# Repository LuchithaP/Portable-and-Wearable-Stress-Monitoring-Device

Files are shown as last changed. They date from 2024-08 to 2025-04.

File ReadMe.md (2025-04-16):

# Portable and Wearable Stress Monitoring Device

A wearable health monitoring system that tracks multiple physiological parameters to help users monitor and manage stress levels.

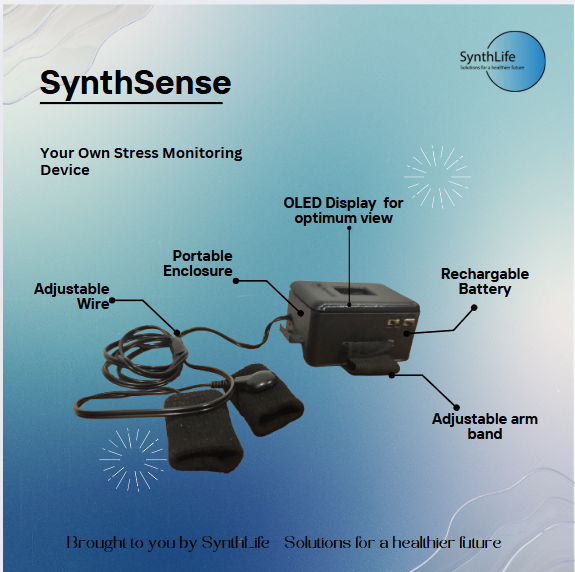
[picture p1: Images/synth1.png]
Device Image


## Overview

This project was developed as part of the EN1190-Engineering Design Project. The device combines multiple sensors to accurately measure physiological indicators of stress and provide real-time feedback to users.

## Features

- **Portable and Wearable Design**: Compact form factor for everyday use
- **Multi-Sensor Approach**: Uses multiple physiological parameters for more accurate stress detection
- **Real-Time Monitoring**: Provides immediate feedback on current stress levels
- **User-Friendly Interface**: Simple display with easy-to-understand stress level indicators

## Hardware Components

### Main Components
- ESP12E microcontroller with built-in WiFi
- Galvanic Skin Response (GSR) sensor
- Temperature sensor (MLX90614)
- Heart rate and SpO2 sensor (MAX30100)
- OLED Display (DM0037)
- 3.7V 1000mAh Rechargeable LiPo Battery

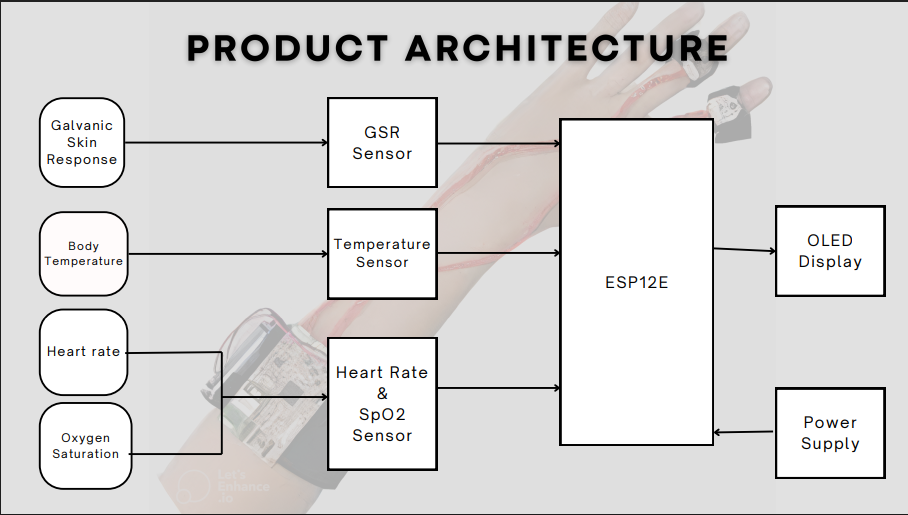
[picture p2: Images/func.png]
Hardware Block Diagram


### Hardware Specifications

#### ESP12E
- Operating voltage: 2.2V to 3.6V
- Operating temperature: -40°C to +125°C
- Working current: 240mA (MAX)
- Built-in WiFi capability

#### Heart Rate & SpO2 Sensor (MAX30100)
- Operating voltage: 1.8V to 3.3V
- Fast data output capability
- Built-in temperature sensor for environmental compensation

#### Temperature Sensor (MLX90614)
- Operating voltage: 3-5V
- Range: -40°C to +125°C (ambient) | -70°C to 380°C (object)
- Accuracy: ±0.5°C

#### Galvanic Skin Response Sensor
- Operating voltage: 3.3-5V
- Measures electrical conductance of skin

#### OLED Display (DM0037)
- Operating voltage: 3.3V–5V DC
- Low power consumption: 0.04W during normal operation
- Working temperature: -30°C to 80°C

## Shematic Design
The schematic was designed using Altium Designer.

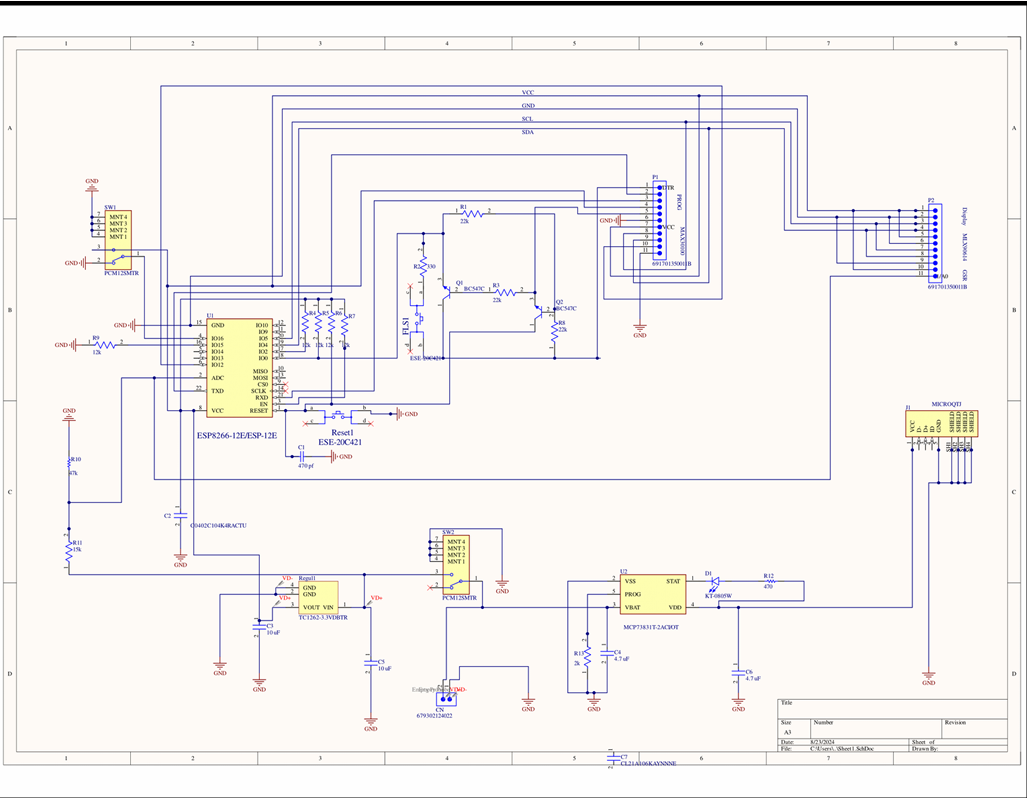
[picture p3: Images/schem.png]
PCB Design


## Enclosure Design

The device features a custom 3D-printed enclosure designed for comfort and usability.

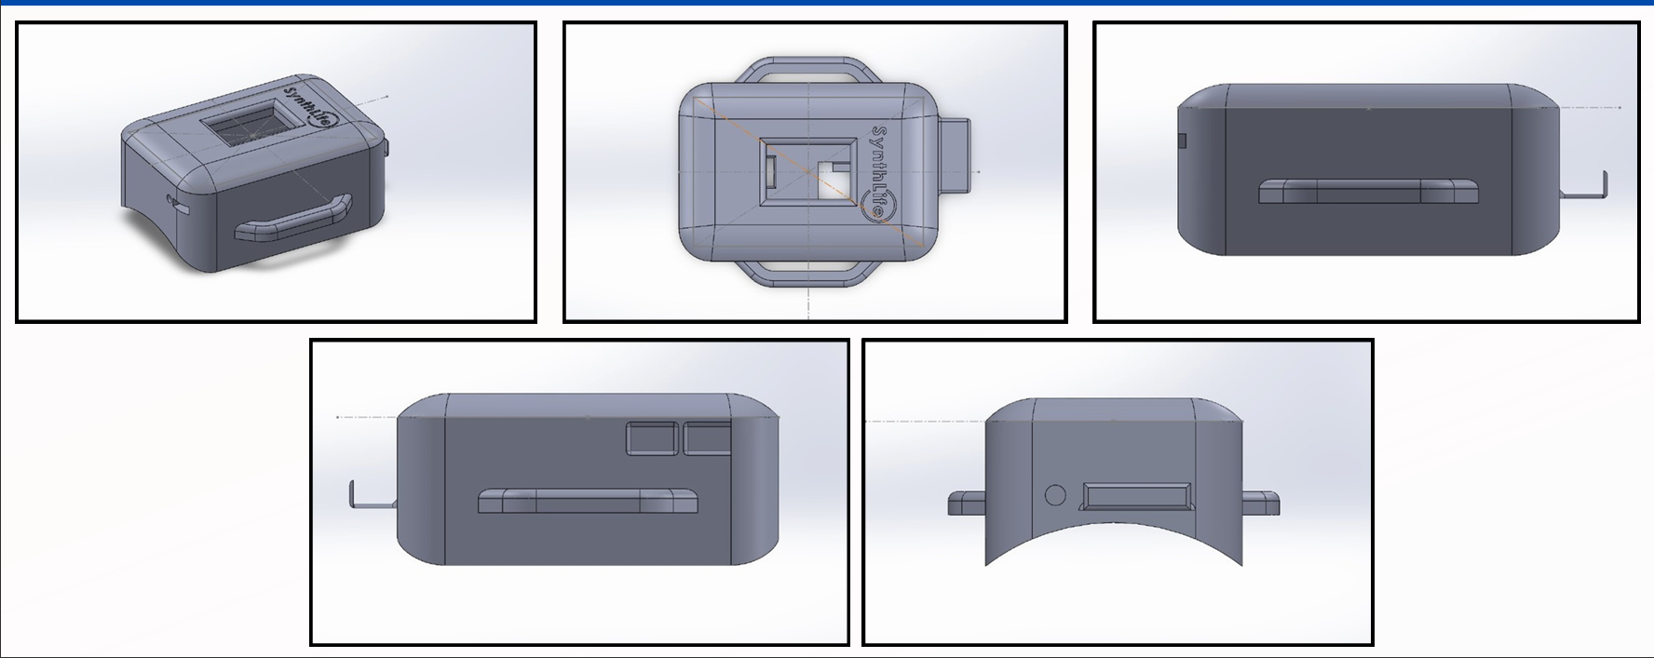
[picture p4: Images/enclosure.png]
Enclosure Design


## How It Works

The device uses an algorithm that analyzes data from multiple sensors to determine the user's stress level:

1. **Data Collection**: Continuously monitors GSR, body temperature, and heart rate
2. **Data Processing**: Applies algorithms to analyze sensor readings
3. **Stress Evaluation**: Categorizes stress levels as Relaxed, Calm, Anxious, or Stressed
4. **User Feedback**: Displays the current stress level on the OLED screen

### Algorithm Parameters

| Parameter | Low | Medium | High | Very High |
|---|-----|---|---|---|
| GSR | < 2 | 2 - 4 | 4 - 6 | > 6 |
| Temperature (°C) | < 35 | 35 - 37 | 37 - 38.5 | > 38.5 |
| Heart Rate (BPM) | 60 - 70 | 70 - 90 | 90 - 100 | > 180 |

## Usage Notes

For accurate readings, the device should be used under the following conditions:
- Normal resting state (not during physical activities)
- GSR sensor needs calibration for individual users
- Consistent positioning on the body

## Development Process

### PCB Design
The PCB was designed using Altium Designer and features two separate units:
- Power Supply Unit
- Main Circuit

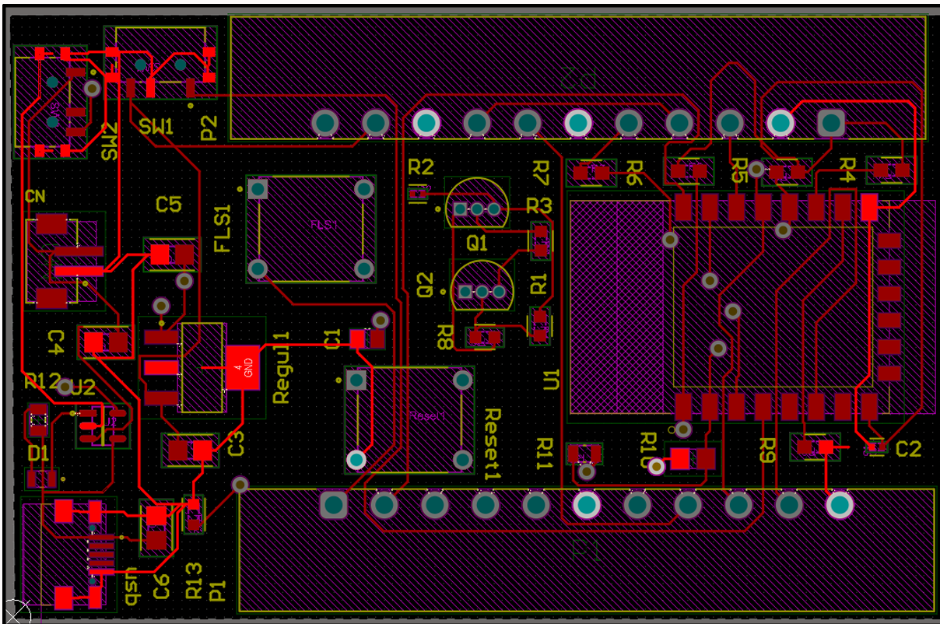
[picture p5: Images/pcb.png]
PCB Layout


### Known Issues and Solutions
During testing, we identified and resolved several issues:
- Insufficient input voltage to the regulator
- High resistance in power lines causing current limitations
- Grounding issues with switches
- Current draw issues with the ESP12E chip

## Team Members

- **P.L.P. Perera**: Microcontroller Programming and Testing, Documentation, Assembling Components, PCB design
- **S.R.N. Fernando**: Market Analysis, Enclosure Design, Assembling Components, Soldering
- **G.M.L. Dulsara**: Microcontroller Programming and Testing, Documentation, Assembling Components, Market Analysis
- **M.H.K. Yashodhara**: Microcontroller Programming and Debugging, Documentation, Budget Coordination, Assembling Components

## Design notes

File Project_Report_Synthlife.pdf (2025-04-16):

# Portable and Wearable Stress Monitoring Device

BM1190 - Engineering Design Project

August 24, 2024

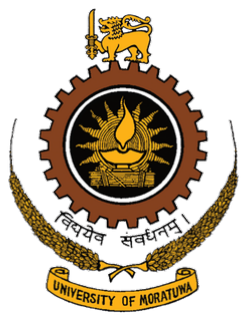
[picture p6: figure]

## Group Members

- DULSARA G.M.L. 220146A
- FERNANDO S.R.N. 220169V
- PERERA.P.L.P 220472T
- YASHODHARA.M.H.K 220735E

## Contents

1 Problem Definition | 3
2 Solution | 4
3 Initial Sketches | 5
4 PCB Schematic Design | 6
5 Solidwork enclosure | 9
6 Software Implementation | 10
7 Hardware Specifications | 11
8 Marketing and Sales | 13
9 Budget and Product Pricing | 14
10 Task Allocation | 14

## 1 Problem Definition

We started doing a survey on 18th March regarding the problems associated with mental stress. The analytics of the survey is as follows.
Out of the over 100 participants who took part in our survey, about 90% of the sample are aware of mental health issues, as shown in Figure 1. These people belonged to several age categories, with the majority being 18 - 25 years old, as depicted in Figure 2.

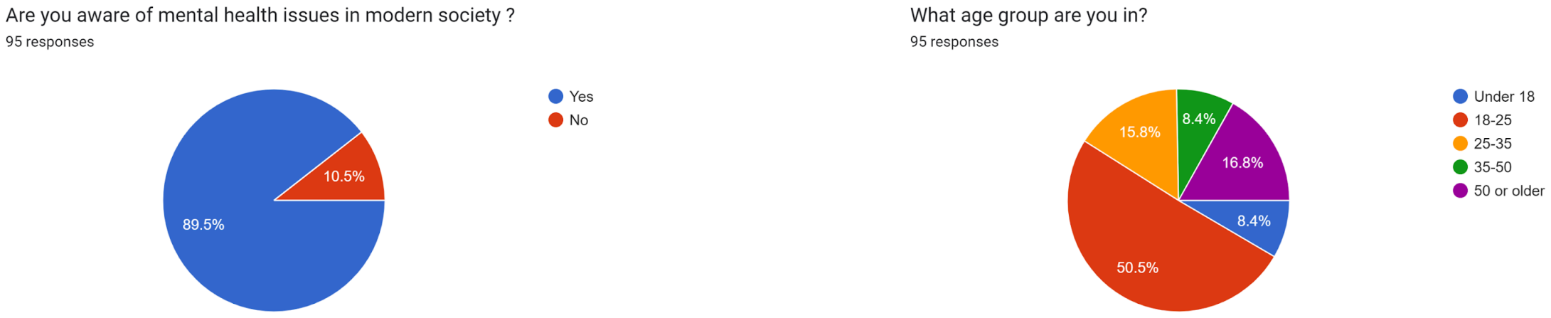
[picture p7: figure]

Figure 1: Awareness | Figure 2: Age Group

Figure 3 shows how often they get stressed, with most people getting stressed daily or once every 2-3 days. Figure 4 shows whether they would like to measure stress levels often with a device. Almost 85% are interested in a device that can monitor their stress levels.

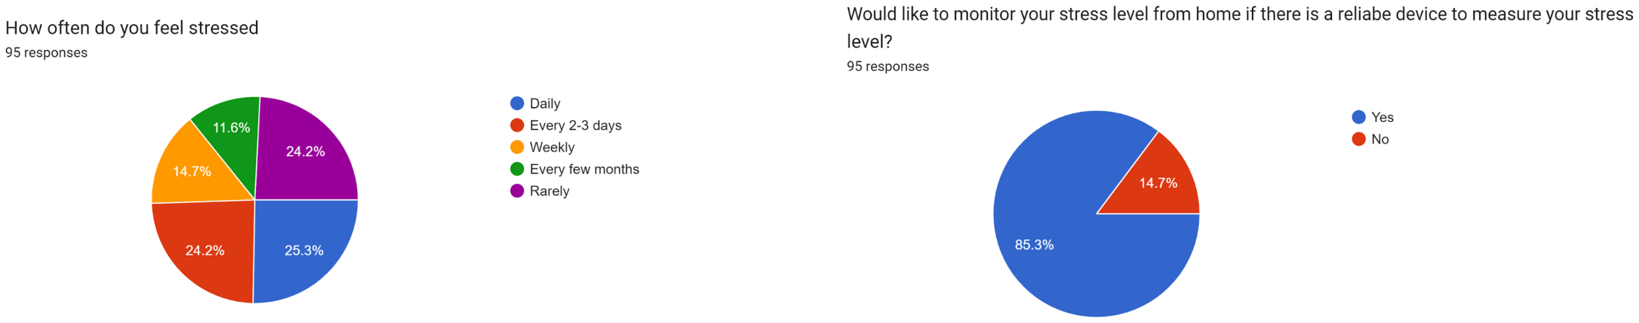
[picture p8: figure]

Figure 3: Stress Frequency | Figure 4: Interest in Stress Monitoring Device

The survey results indicate a significant need for a portable wearable stress monitoring device in the market. With 90% of participants aware of mental health issues and a large majority experiencing stress daily or every few days, the demand for effective stress management solutions is evident. Moreover, nearly 85% of respondents expressed interest in a device that can monitor their stress levels regularly. This data shows the growing necessity for accessible, real-time stress monitoring technology, especially among young adults, making it a crucial innovation for improving mental well-being.

## 2 Solution

### 2.1 Overview of the Solution

Our solution is a portable and wearable device designed to monitor stress levels with high accuracy. By integrating multiple advanced sensors, the device provides precise measurements of physiological indicators associated with stress. It is user-friendly, ensuring it can be comfortably worn throughout the day, making stress management both accessible and convenient. The primary goal of this device is to help mitigate the severe consequences of mental stress, such as diabetes, heart attack, depression, and even suicide. By offering real-time insights into stress levels, our product aims to enhance overall mental well-being and prevent stress-related health issues.

### 2.2 Sensor Technology

The effectiveness of our solution is grounded in its use of cutting-edge sensor technology. The device is equipped with the following sensors:

- Heart Rate and SpO2 Sensor (MAX30100): This sensor is crucial for monitoring heart rate and blood oxygen saturation (SpO2), both key indicators of stress. By tracking variations in these parameters, the device can accurately assess the user’s stress levels in real time.
- Temperature Sensor (MLX90614): The MLX90614 is a non-contact infrared temperature sensor that measures skin temperature, another critical factor in stress detection. Changes in skin temperature can indicate physiological responses to stress, contributing to the device’s overall accuracy.
- Galvanic Skin Response Sensor: This sensor measures the electrical conductivity of the skin, which varies with sweat gland activity. Since stress typically increases sweat production, this sensor provides additional data that enhances the accuracy of stress monitoring.

### 2.3 User-Focused Design

Our device is designed with the user in mind, ensuring both portability and wearability. The compact and lightweight form factor allows users to wear the device comfortably throughout the day without inconvenience. Its design is discreet, making it suitable for various settings, whether at work, home, or on the go. The user interface is intuitive, making it easy for users to understand their stress levels and take timely actions based on the feedback provided.

### 2.4 Impact on Mental Health

The primary purpose of our solution is to address the pressing issue of mental stress and its severe health consequences. Chronic stress is a major contributor to serious conditions such as diabetes, heart attacks, depression, and even suicide. By providing real-time monitoring, our device enables users to recognize early signs of stress and take proactive measures to manage it. This timely intervention can significantly reduce the risk of developing stress-related health issues, ultimately improving the user’s mental health and quality of life.

## 3 Initial Sketches

### 3.1 Device Overview

The proposed device to measure stress levels and vital signs based on sensor fusion is able to measure a person’s mental health (stress levels) and physical health (vital signs) simultaneously.. In this tool, the vital signs measured are oxygen saturation level (SpO2), body temperature, and heart rate. The stress level is measured by combining the galvanic skin response (GSR), body temperature, and heart rate sensor readings, which are then processed by a fuzzy logic algorithm in the microcontroller to determine the stress level. And then the determined stress level is displayed using the LCD. A system block diagram of the device is presented in the figure above.

### 3.2 Product Architecture

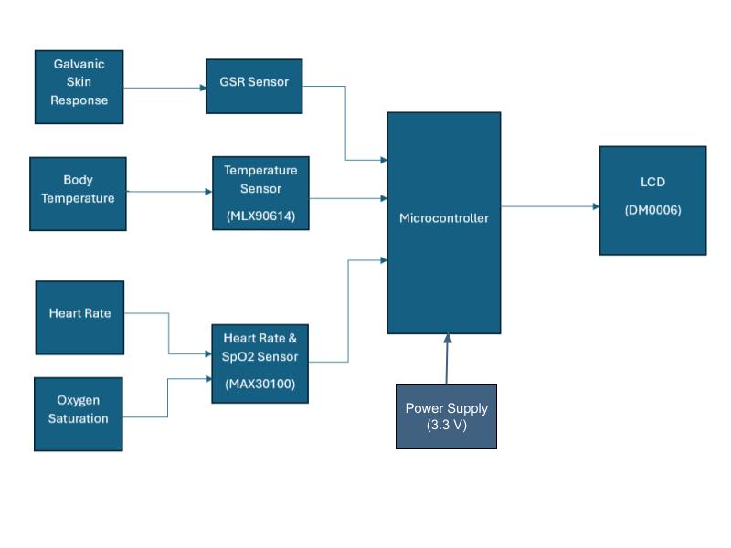
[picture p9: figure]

Figure 5: Product Architecture

### 3.3 Initial Enclosure Design

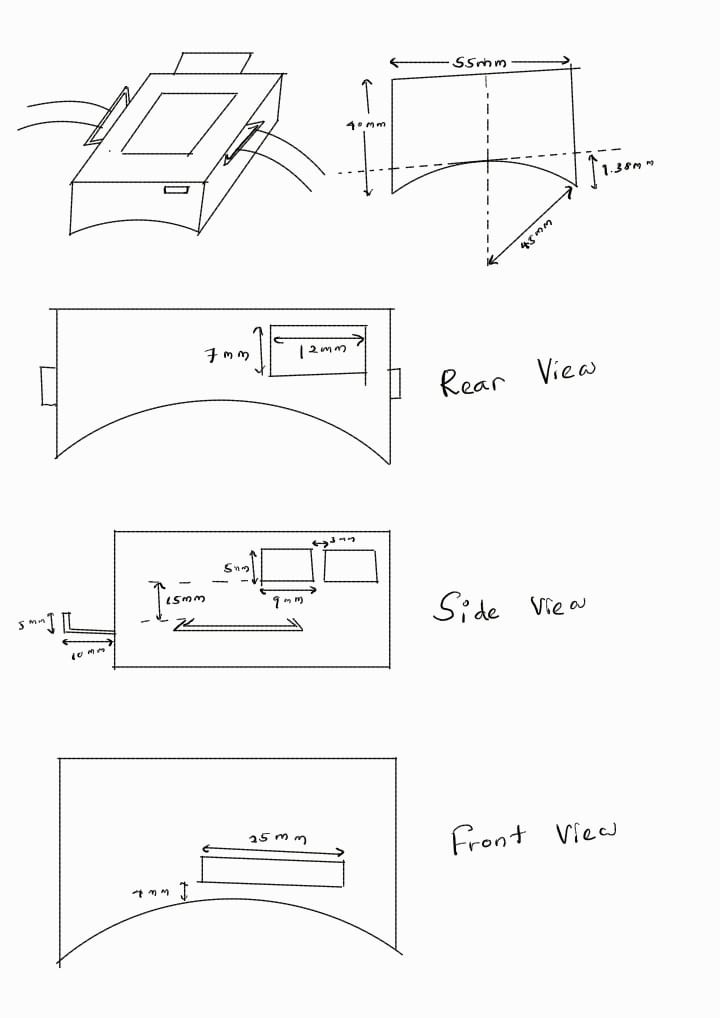
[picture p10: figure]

Figure 6: Initial Sketch of the enclosure

## 4 PCB Schematic Design

The PCB for this project integrates an ESP8266-12E microcontroller unit, responsible for processing sensor data and handling communication with external devices. Key sensors include the MAX30100 (for SpO2 and heart rate) and the MLX90614 (temperature sensor), interfaced through I2C lines, and a Galvanic Skin Response sensor. The board features proper power management using voltage regulators and capacitors to ensure stable operation.
The design ensures minimal noise and interference, with clear separation of analog and digital traces. The compact and efficient layout facilitates easy deployment in wearable applications, making it suitable for continuous real-time monitoring of vital parameters related to stress levels.

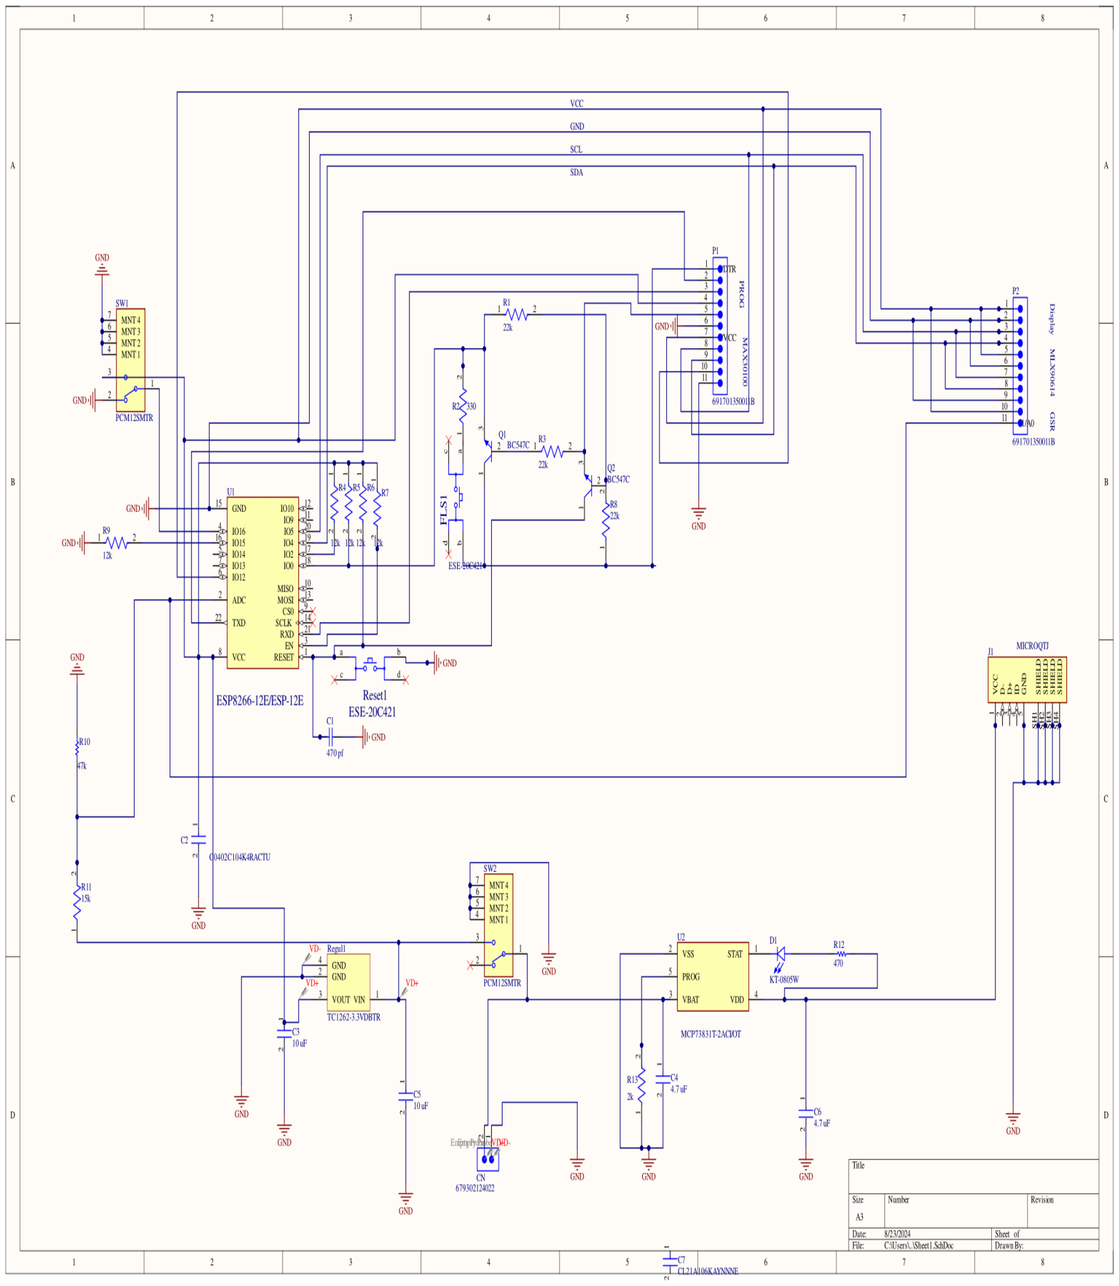
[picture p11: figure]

Figure 7: Schematic design

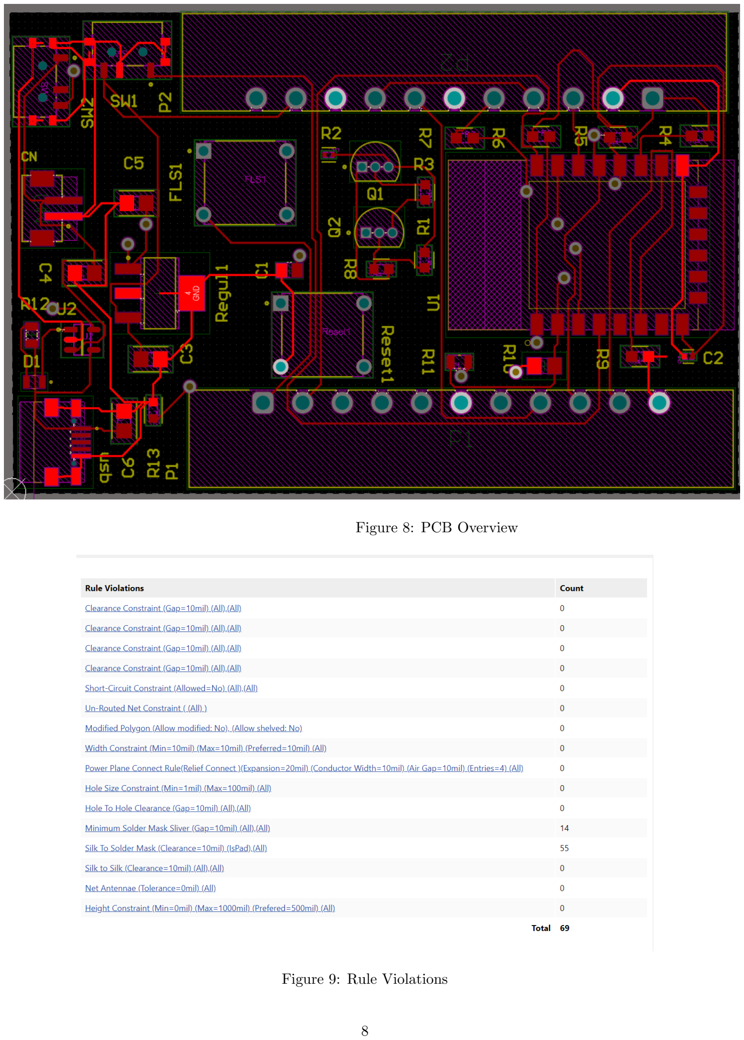
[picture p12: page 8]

Figure 8: PCB Overview

Figure 9: Rule Violations

## 5 Solidwork enclosure

### 5.1 Overview

The enclosure for our stress monitoring device was designed using SolidWorks to ensure precision and functionality. Leveraging SolidWorks’ advanced modeling and simulation tools, we crafted a robust design that balances durability with user comfort. The model features a sleek, contoured shape that conforms to the wearer’s body, minimizing discomfort during extended use. Through SolidWorks’ simulation capabilities, we conducted thorough stress tests and thermal analyses to ensure the enclosure withstands environmental factors and internal heat generation. The design includes effective sensor placement and user interaction. Additionally, the detailed 3D models and assemblies created in SolidWorks streamline the manufacturing process, ensuring that all components fit together seamlessly and meet high-quality standards.

5.2 3D View

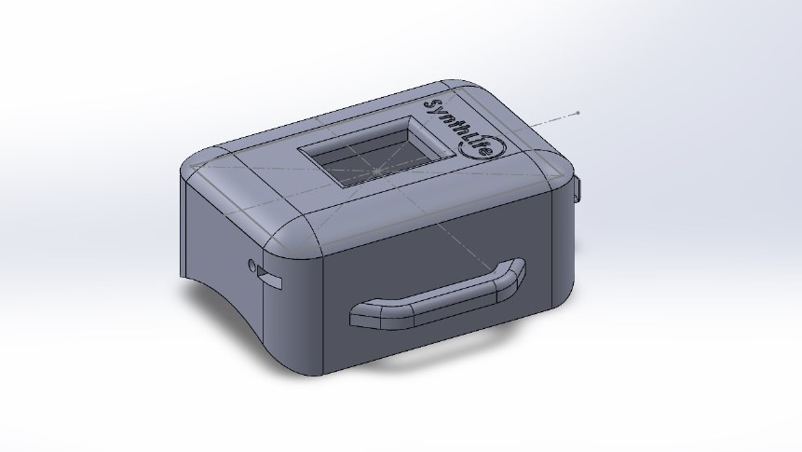
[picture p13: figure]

## 6 Software Implementation

### 6.1 Overview

The software implementation of our stress monitoring device is powered by C++, enabling efficient and responsive data processing. The C++ code interfaces directly with the device’s sensors, capturing physiological data such as heart rate variability and skin conductance. Advanced algorithms, implemented in C++, analyze this data in real-time to determine the user’s stress levels. The software is designed to be lightweight and fast, ensuring smooth operation while providing real-time feedback through a user-friendly interface. Additionally, it supports customizable alerts and long-term data logging, allowing users to monitor and manage their stress effectively

### 6.2 Algorithm

GSR Value | Temperature | Heart Rate
Low | Medium | High | Very High
Low | Low | Relax | Anxious | Anxious | Anxious
| Medium | Relax | Calm | Calm | Calm
| High | Calm | Calm | Calm | Anxious
| Very High | Relax | Calm | Calm | Relax
Medium | Low | Anxious | Anxious | Anxious | Stress
| Medium | Calm | Calm | Anxious | Anxious
| High | Calm | Calm | Calm | Anxious
| Very High | Relax | Calm | Calm | Relax
High | Low | Anxious | Calm | Anxious | Anxious
| Medium | Anxious | Anxious | Anxious | Anxious
| High | Calm | Calm | Anxious | Anxious
| Very High | Calm | Calm | Anxious | Stress
Very High | Low | Anxious | Anxious | Stress | Anxious
| Medium | Anxious | Anxious | Anxious | Stress
| High | Anxious | Calm | Anxious | Stress
| Very High | Calm | Calm | Anxious | Stress

Table 1: GSR, Temperature, and Heart Rate Table

Threshold Values | GSR | Temperature (°C) | BPM
Low | < 2 | < 35 | 60 - 70
Medium | 2 - 4 | 35 - 37 | 70 - 90
High | 4 - 6 | 37 - 38.5 | 90 - 100
Very High | > 6 | > 38.5 | > 180

Table 2: Threshold Values for GSR, Temperature, and BPM

## 7 Hardware Specifications

### 7.1 Overview

Our stress monitoring device incorporates four essential sensors to accurately assess an individual’s physiological state:heart rate,body temperature,SpO2 (oxygen saturation), and Galvanic Skin Response (GSR). By continuously collecting data from these sensors, the device computes a comprehensive stress indicator that determines the user’s stress levels in real-time. This calculated value is then clearly displayed, enabling timely and effective monitoring of the patient’s stress condition.

Now Let’s dive into more detailed hardware analysis

### 7.2 Microcontroller

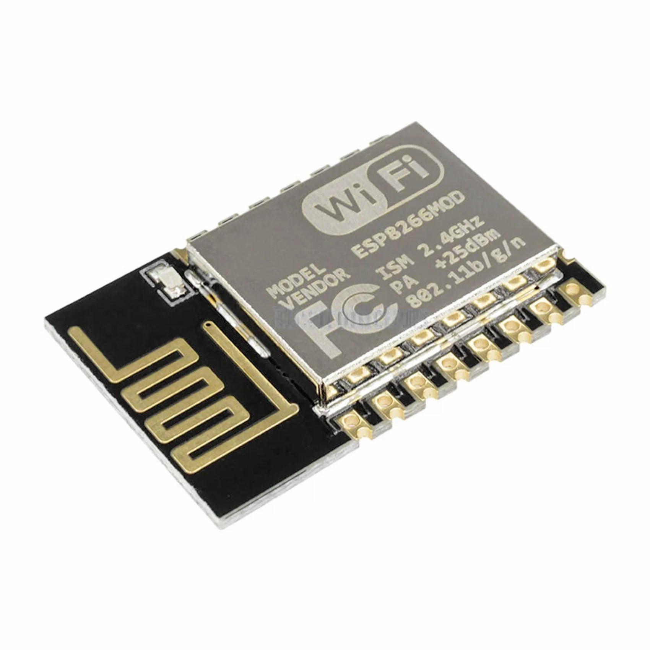
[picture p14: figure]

Figure 10: Microcontroller

For the microcontroller, we’ve used an ESP12E with the following features:

- Built-in Wi-Fi
- 2.2V to 3.6V operating voltage
- -40°C to +125°C operating temperature
- Working current: 240mA (MAX)

### 7.3 Power Supply

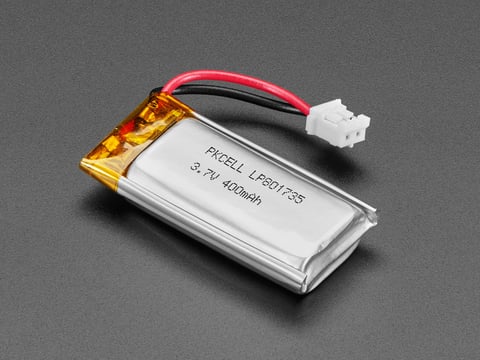
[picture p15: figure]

Figure 11: Power Supply

For the power supply we’ve used a rechargable LiPo Battery.

- BNominal Voltage: 3.7V
- Capacity: 1000mAh

### 7.4 Heart Rate and SpO2

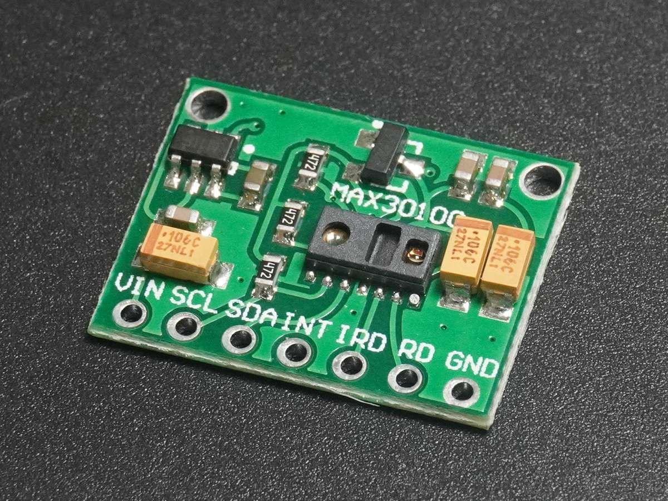
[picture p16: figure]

Figure 12: Heart Rate and SpO2 Sensor

To get the readings for the heart rate and SpO2 values we’ve used MAX30100 sensors with following specifications

- 1.8 to 3.3V Operating voltage rage
- Fast Data Output Capability
- Built-in temperature sensor on the module, used to compensate for environmental changes and calibrate the measurements.

### 7.5 Temperature

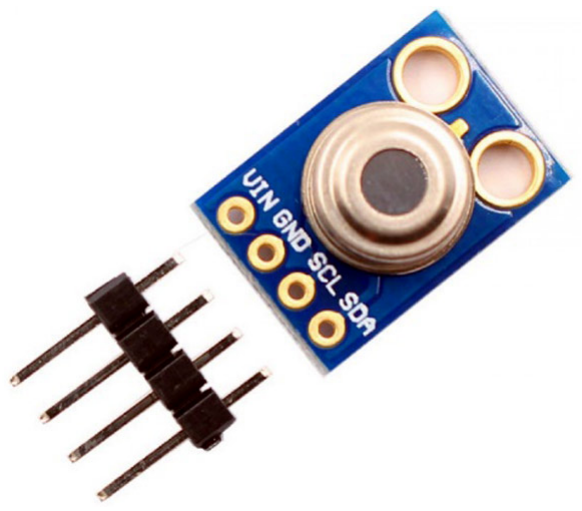
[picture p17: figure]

Figure 13: Temperature Sensor

To get the readings for the body temperature we’ve used MAX30100 sensors with following specifications.

- 3V-5V operating voltage
- Range -40°C to +125°C (ambient)—-70°C-380°C (object)
- Accuracy ±0.5
◦C

### 7.6 Galvanic Skin Response

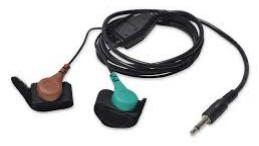
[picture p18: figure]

Figure 14: GSR Sensor

The GSR sensor has following specifications

- 3.3V-5V operating voltage
- Measures electrical conductance of skin

### 7.7 Display

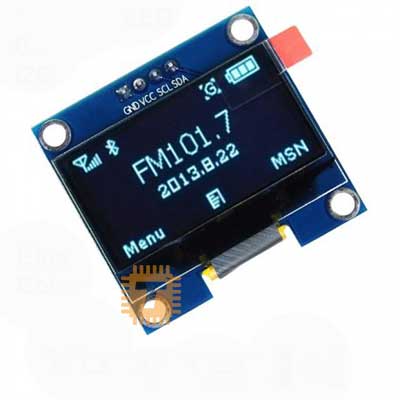
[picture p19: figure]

Figure 15: OLED Display

We’ve used an OLED Display (DM0037) as our display with following specifications.

- Low power consumption: 0.04 W during normal operation
- Support wide voltage: 3.3V–5V DC
- Working temperature: -30 to 80 degrees

## 8 Marketing and Sales

### 8.1 Marketing Strategies

- Target Audience Identification: Focus on health-conscious consumers, corporate partnerships, and healthcare providers to expand market reach.
- Product Differentiation: Highlight the unique selling points of the device, such as sensor fusion technology, portability, user-friendliness, and affordability. Offer customization options for personalized features.
- Digital and Content Marketing: Leverage social media campaigns, influencer partnerships, educational blogs, and videos to create engaging content. Host webinars and workshops to educate potential customers.
- Strategic Partnerships:Establish collaborations with health and fitness brands and telehealth services to enhance the device’s visibility and integration into wellness routines.
- Regulatory and Certification Marketing: Emphasize health certifications, data privacy, and compliance with standards to build consumer trust and credibility.

### 8.2 Sales Strategies

- Sales Channels: Distribute the device through e-commerce platforms like Amazon and a dedicated website to ensure a user-friendly shopping experience.Distribute the device through e-commerce platforms like Amazon and a dedicated website to ensure a user-friendly shopping experience.
- Retail Partnerships: Collaborate with health and wellness stores, pharmacies, and tech retailers to expand the device’s availability and reach.
- Customer Feedback and Continuous Improvement: Actively gather user feedback to make ongoing product enhancements, ensuring the device meets customer needs and expectations.

## 9 Budget and Product Pricing

Item | Cost (Rs/=)
Galvanic Skin Response Sensor | 4,934
IR Temperature Sensor Module (MLX90614) | 2,630
Pulse Oximeter SpO2 and Heart-Rate Sensor (MAX30102) | 500
OLED Display | 580
PCB | 4,619
ESP-12E ESP8266 | 690
Enclosure print | 1,521
Other small components | 272
3.7V 1000mah 30C Lipo Battery 701855 | 1,090
Total estimated cost | 16,256
Estimated Product Price | 20,000

Table 3: Breakdown of the Estimated Project Costs

## 10 Task Allocation

Perea P.L.P. - Circuit Design, Altium, and PCB Design: Perea P.L.P. was responsible for the core electronics design of the project. This included developing the circuit schematic, selecting appropriate components, and ensuring the circuit met all functional and safety requirements. Utilizing Altium, Perea created the detailed PCB layout, optimizing it for size, power consumption, and signal integrity. Perea also managed the PCB fabrication process, ensuring that the final boards were produced according to the design specifications.

Fernando S.R.N. - SolidWorks and Enclosure Design: Fernando S.R.N. focused on the physical design aspects of the project. Using SolidWorks, Fernando designed the enclosure that houses the electronic components, ensuring it was ergonomic, aesthetically pleasing, and met all required specifications for durability and portability. The design process involved multiple iterations to ensure that the enclosure was compatible with the internal components while providing sufficient protection and ease of use for the end user.

Dulsara G.M.L. - Survey Analyzing, Microcontroller Programming and Testing, Market Analyzing, Presentation Designing Dulsara G.M.L. played a multifaceted role in the project. Dulsara led the analysis of survey data to gather insights into user needs and preferences, which informed the product development process. Additionally, Dulsara handled the microcontroller programming, focusing on implementing and testing the firmware required for sensor integration and data processing. Market analysis was also conducted to identify potential market segments and competitors. Finally, Dulsara was responsible for designing the presentation, ensuring that it effectively communicated the project’s objectives, methodologies, and outcomes.

Yashodhara M.H.K. - Product Idea Surveying, Microcontroller Programming and Debugging, Product Marketing, Budget Coordinating, Final Report Making: Yashodhara M.H.K. took the lead in the initial product idea survey, gathering and analyzing data to shape the project’s direction. Yashodhara also contributed to the microcontroller programming, focusing on debugging and optimizing the code. In addition to these technical tasks, Yashodhara managed the product marketing strategy, identifying key selling points and potential customer segments. Yashodhara also coordinated the budget, ensuring that the project stayed within financial constraints, and was responsible for compiling and editing the final report, ensuring it was comprehensive and well-structured.

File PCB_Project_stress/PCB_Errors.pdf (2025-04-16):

# Synthlife Stress Monitoring Device

31/08/2024

## Identified Errors in PCB

### 1. Via and Trace Length Issues

(a) Issue: Two vias used to connect EN and R6 introduce high impedance. Therefore, less current is drawn. Due to that, the chip is not properly getting booted.
(b) Issue: The distance between R6 and EN pins are long, causing timing errors.
- Solution: Directly connect EN and R6 without vias.

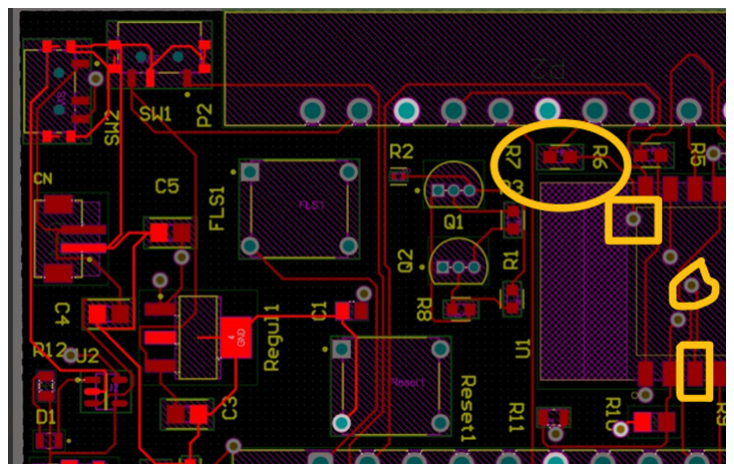
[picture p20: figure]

Figure 1: EN and R6 connection issue.

### 2. Closely Placed Vias

Issue: Closely placed vias introduce high impedance, restricting the current.

- Solution: Use a minimum number of vias for routing and keep them further away from each other.

1

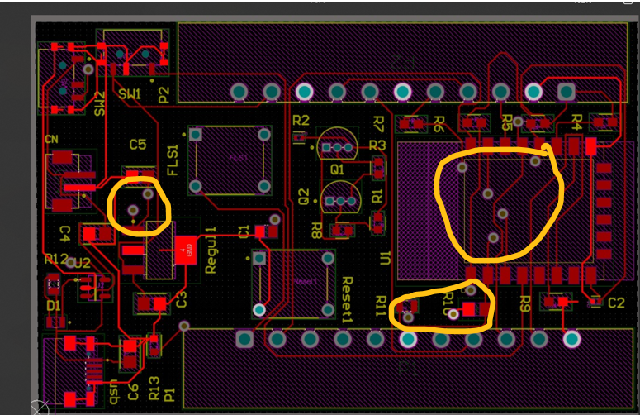
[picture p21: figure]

Figure 2: Closely placed vias causing high impedance.

### 3. Trace and Regulator Issues

Issue: The distance between the Regulator output pin and VCC of the chip is high, causing an increase in resistance due to the length of the traces. This results in insufficient current supply.

- Solution: Make the traces wider. Replace the regulator with a higher current output (e.g., avoid using AMS1117 due to heat dissipation issues).

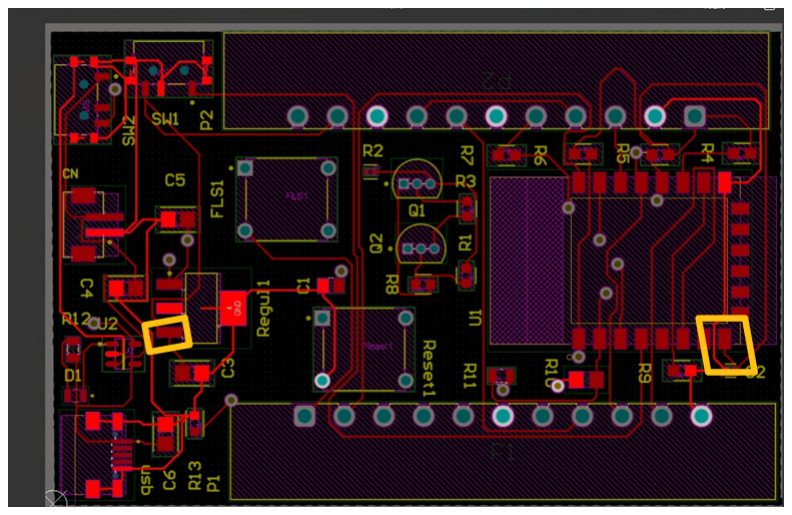
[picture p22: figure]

Figure 3: Trace length and regulator issues.

### 4. GPIO2 is not correctly pulled up

Issue: When booting GPIO2 should be 1. Since we have used 12k resistor as the pull up resistor funcionality of GPIO2 is corrupted.

- Solution: Using a 2.2k resistor to pull-up GPIO2 or else leave it as a floating pin and control GPIO0 during reboot to switch between automatic flash downloading and normal boot up.

2

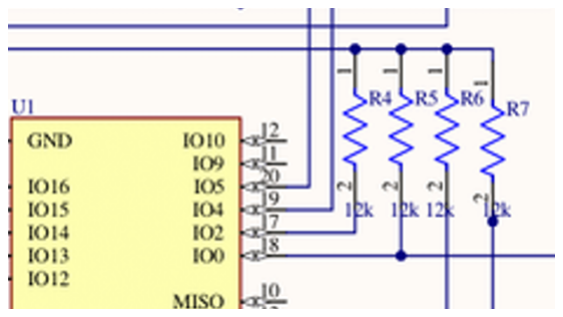
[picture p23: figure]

Figure 4: GPIO2 pulled-up wrongly

3

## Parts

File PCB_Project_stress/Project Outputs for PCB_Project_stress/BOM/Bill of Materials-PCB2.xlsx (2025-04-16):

Comment | Description | Designator | Footprint | LibRef | Quantity
4.7 nF |  | C1 | CAPC2013X135X50LL15T20 | CMP-2007-03450-1 | 1
C0402C104K4RACTU | CAP CER 0.1UF 16V X7R 0402 | C2 | FP-C0402-BB-MFG | CMP-2008-02108-2 | 1
10 uF | CL21 Series 0805 10uF 25V ±10% Tolerance X5R Multilayer Ceramic Chip Capacitor | C3, C5 | FP-CL21-IPC_A | CMP-13271-002975-1 | 2
4.7 uF | CL21 Series 0805 4.7uF 25V ±10% Tolerance X5R Multilayer Ceramic Chip Capacitor | C4, C6 | FP-CL21-IPC_A | CMP-13271-002624-1 | 2
679302124022 |  | CN | 679302124022 | CMP-1502-00721-2 | 1
KT-0805W | Light Emitting Diodes | D1 | LED_KT-0805W | KT-0805W | 1
ESE-20C421 | SWITCH PUSH SPST-NO 0.1A 14V | FLS1, Reset1 | FP-ESE-20C421-MFG | CMP-05613-000006-1 | 2
691701350011B |  | P1, P2 | 691701350011B | CMP-1502-02023-2 | 2
BC547C | Amplifier Transistor, NPN Silicon, 3-Pin TO-92, Bulk Box | Q1, Q2 | ONSC-TO-92-3-29-11 | CMP-1048-01437-1 | 2
22k | RES Thick Film, 22kΩ, 1%, 0.1W, 100ppm/°C, 0603 | R1, R3, R8 | FP-CRCW0603-e3-IPC_B | CMP-2000-03092-2 | 3
330 | RES Thick Film, 330kΩ, 1%, 0.063W, 100ppm/°C, 0402 | R2 | FP-CRCW0402-e3-IPC_C | CMP-2002-08521-2 | 1
12k | RES Thick Film, 12kΩ, 1%, 0.1W, 100ppm/°C, 0603 | R4, R5, R6, R7, R9 | FP-CRCW0603-e3-IPC_A | CMP-2000-03877-2 | 5
47k |  | R10 | RESC2013X70X40ML20T20 | CMP-2001-00421-1 | 1
15k | RES Thick Film, 15kΩ, 1%, 0.125W, 100ppm/°C, 0805 | R11 | FP-CRCW0805-e3-IPC_C | CMP-2001-04967-2 | 1
470 | Chip Resistor, 470 Ohm, +/- 1%, 125 mW, -55 to 155 degC, 0805 (2012 Metric), RoHS, Tape and Reel | R12 | RESC2013X60X35LL10T20 | CMP-2000-06961-1 | 1
2k | RES 2kΩ 1.00% 0.1W 0603 | R13 | FP-AC0603-IPC_B | CMP-2000-04836-2 | 1
TC1262-3.3VDBTR | 500mA Fixed Output CMOS LDO, 3-Pin SOT-223, Extended Temperature, Tape and Reel | Regul1 | SOT-223-DB3_M | CMP-0136-00481-1 | 1
PCM12SMTR | SWITCH SLIDE SPDT 300MA 6V | SW1, SW2 | FP-PCM12SMTR-MFG | CMP-2000-06884-2 | 2
ESP8266-12E/ESP-12E | This WiFi module has a 32-bit MCU micro and clock speeds supporting 80 MHz or 160 MHz. Supports the RTOS and integrated Wi-Fi MAC/BB/RF/PA/LNA, and has an on-board antenna. | U1 | XCVR_ESP8266-12E/ESP-12E | ESP8266-12E/ESP-12E | 1
MCP73831T-2ACI/OT | IC CONTROLLR LI-ION 4.2V SOT23-5 | U2 | FP-C04-091-OT-IPC_B | CMP-0133-00143-2 | 1
MICROQTJ |  | usb | SHOUHAN_MICROQTJ | MICROQTJ | 1

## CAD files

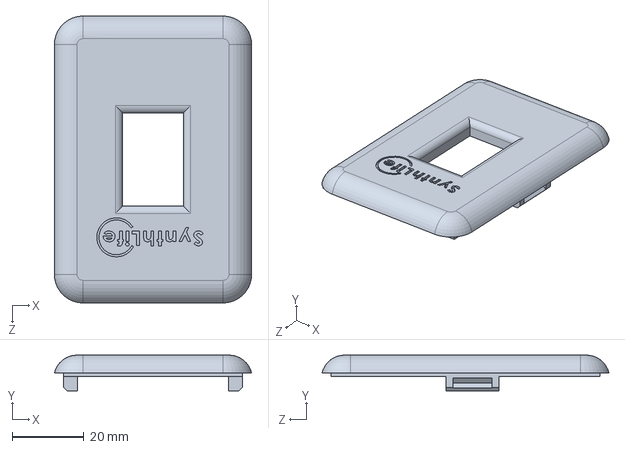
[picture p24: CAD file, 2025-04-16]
enclosure/synthlife design_lid_v2.SLDPRT
55.0 x 10.0 x 80.0 mm

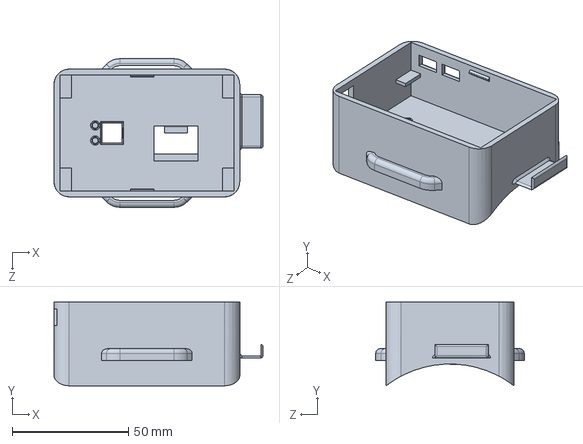
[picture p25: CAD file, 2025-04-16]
enclosure/synthlife design_body_v2.SLDPRT
90.0 x 36.0 x 64.0 mm

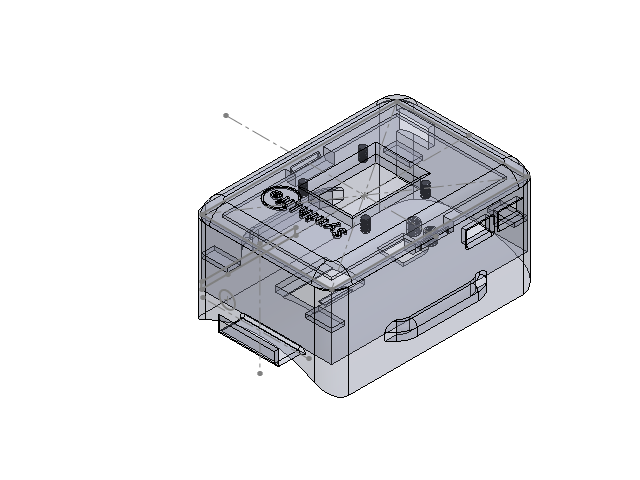
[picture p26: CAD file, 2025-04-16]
enclosure/synthlife_design.SLDASM
synthlife design_lid_v2 - Edid_3
synthlife design_v2_edit3

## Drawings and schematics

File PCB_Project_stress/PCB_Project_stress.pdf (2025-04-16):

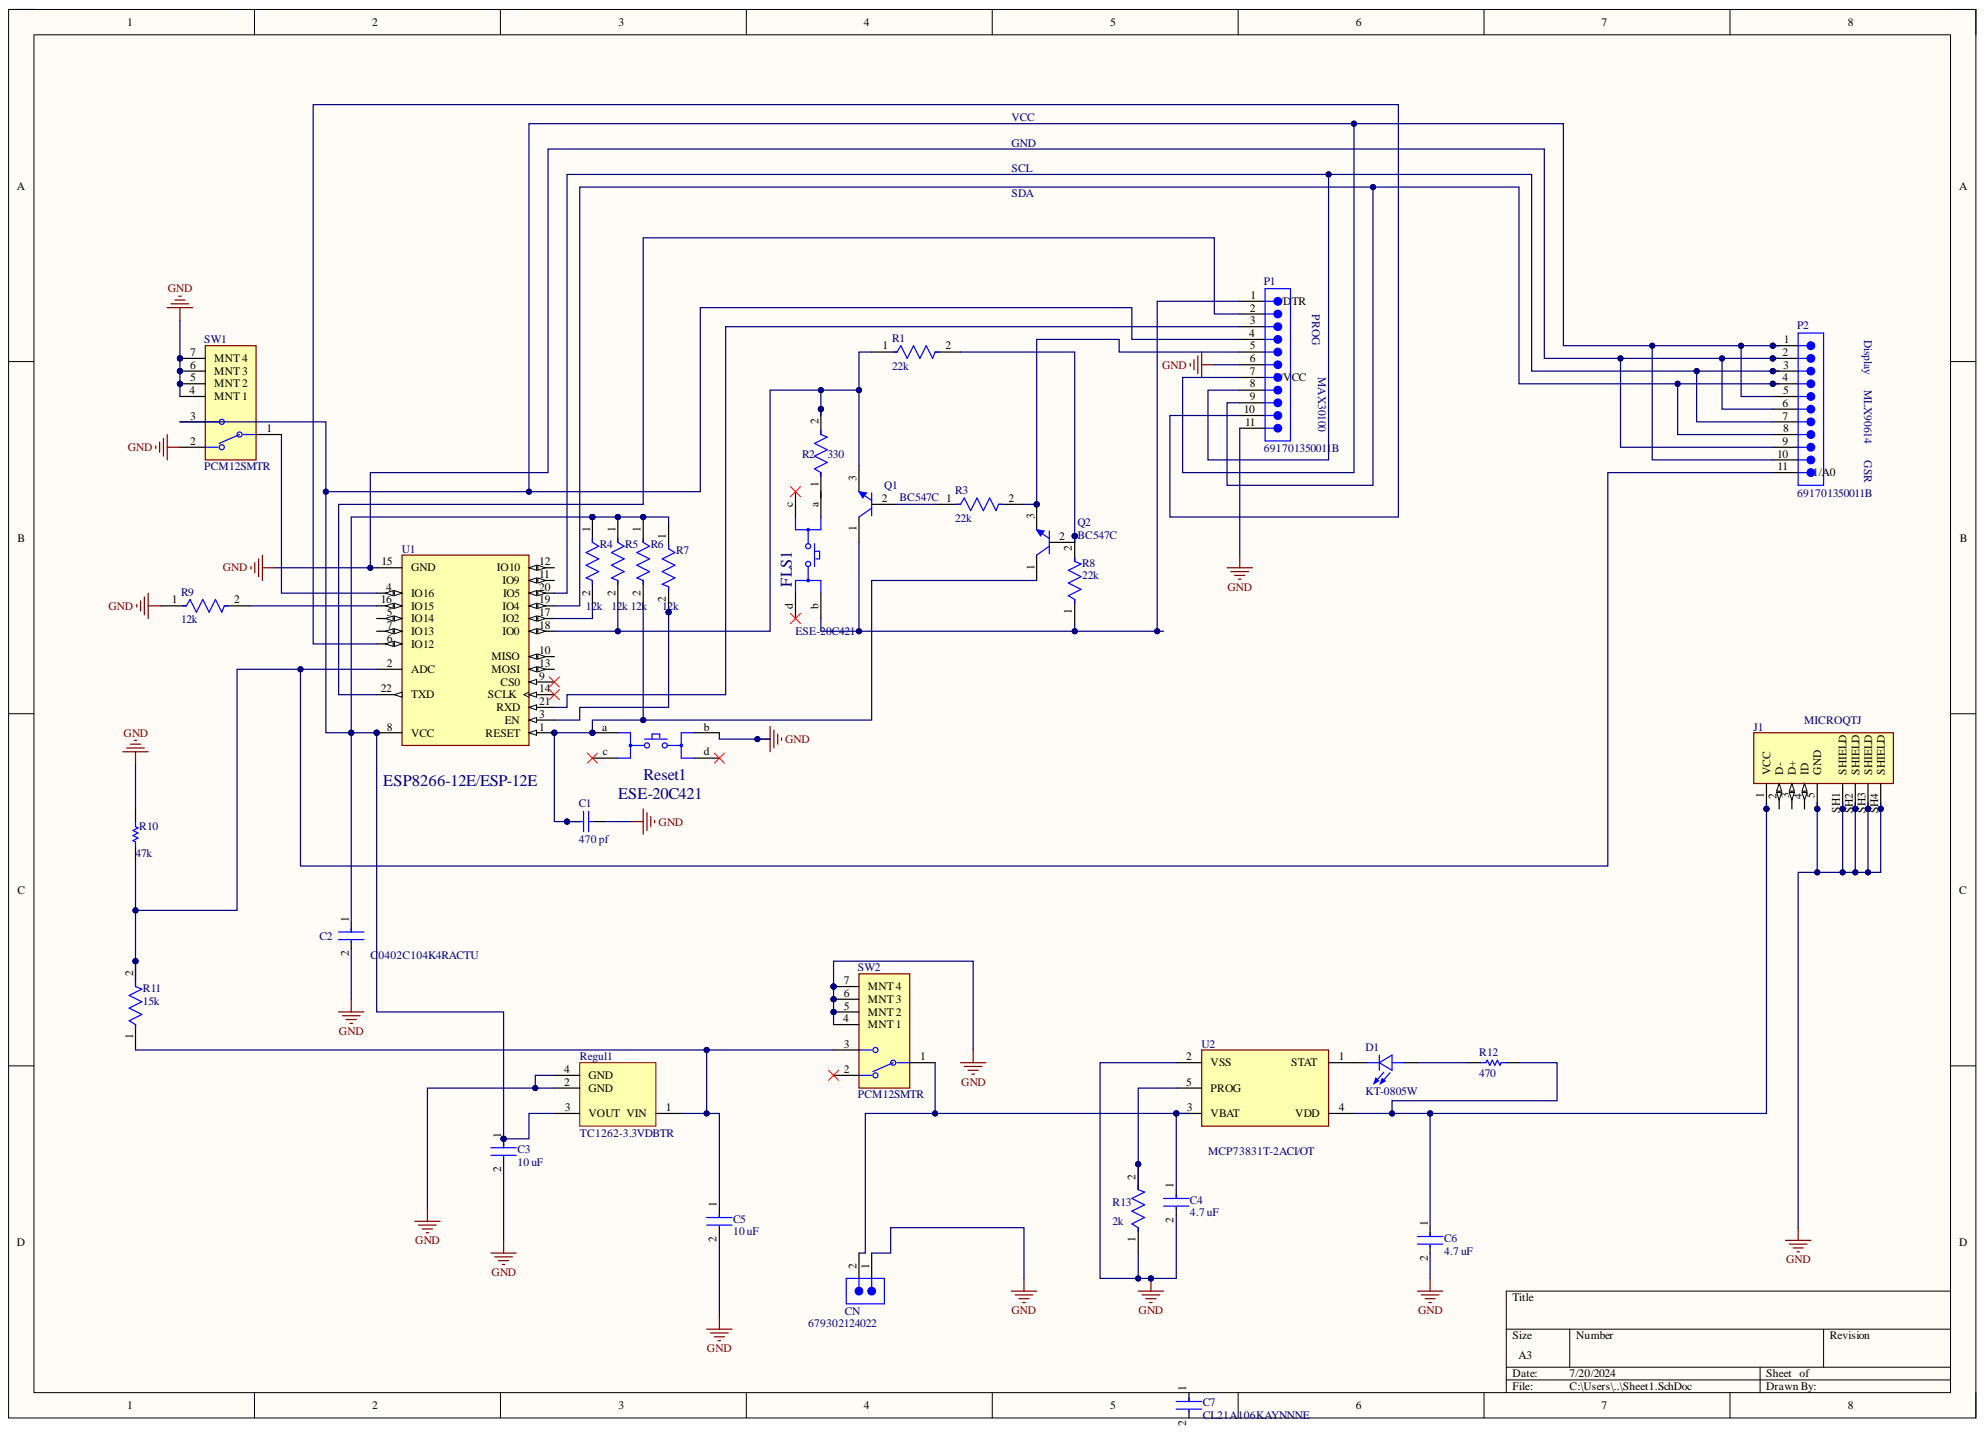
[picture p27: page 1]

GND

SCL

ADC 2

VCC 8

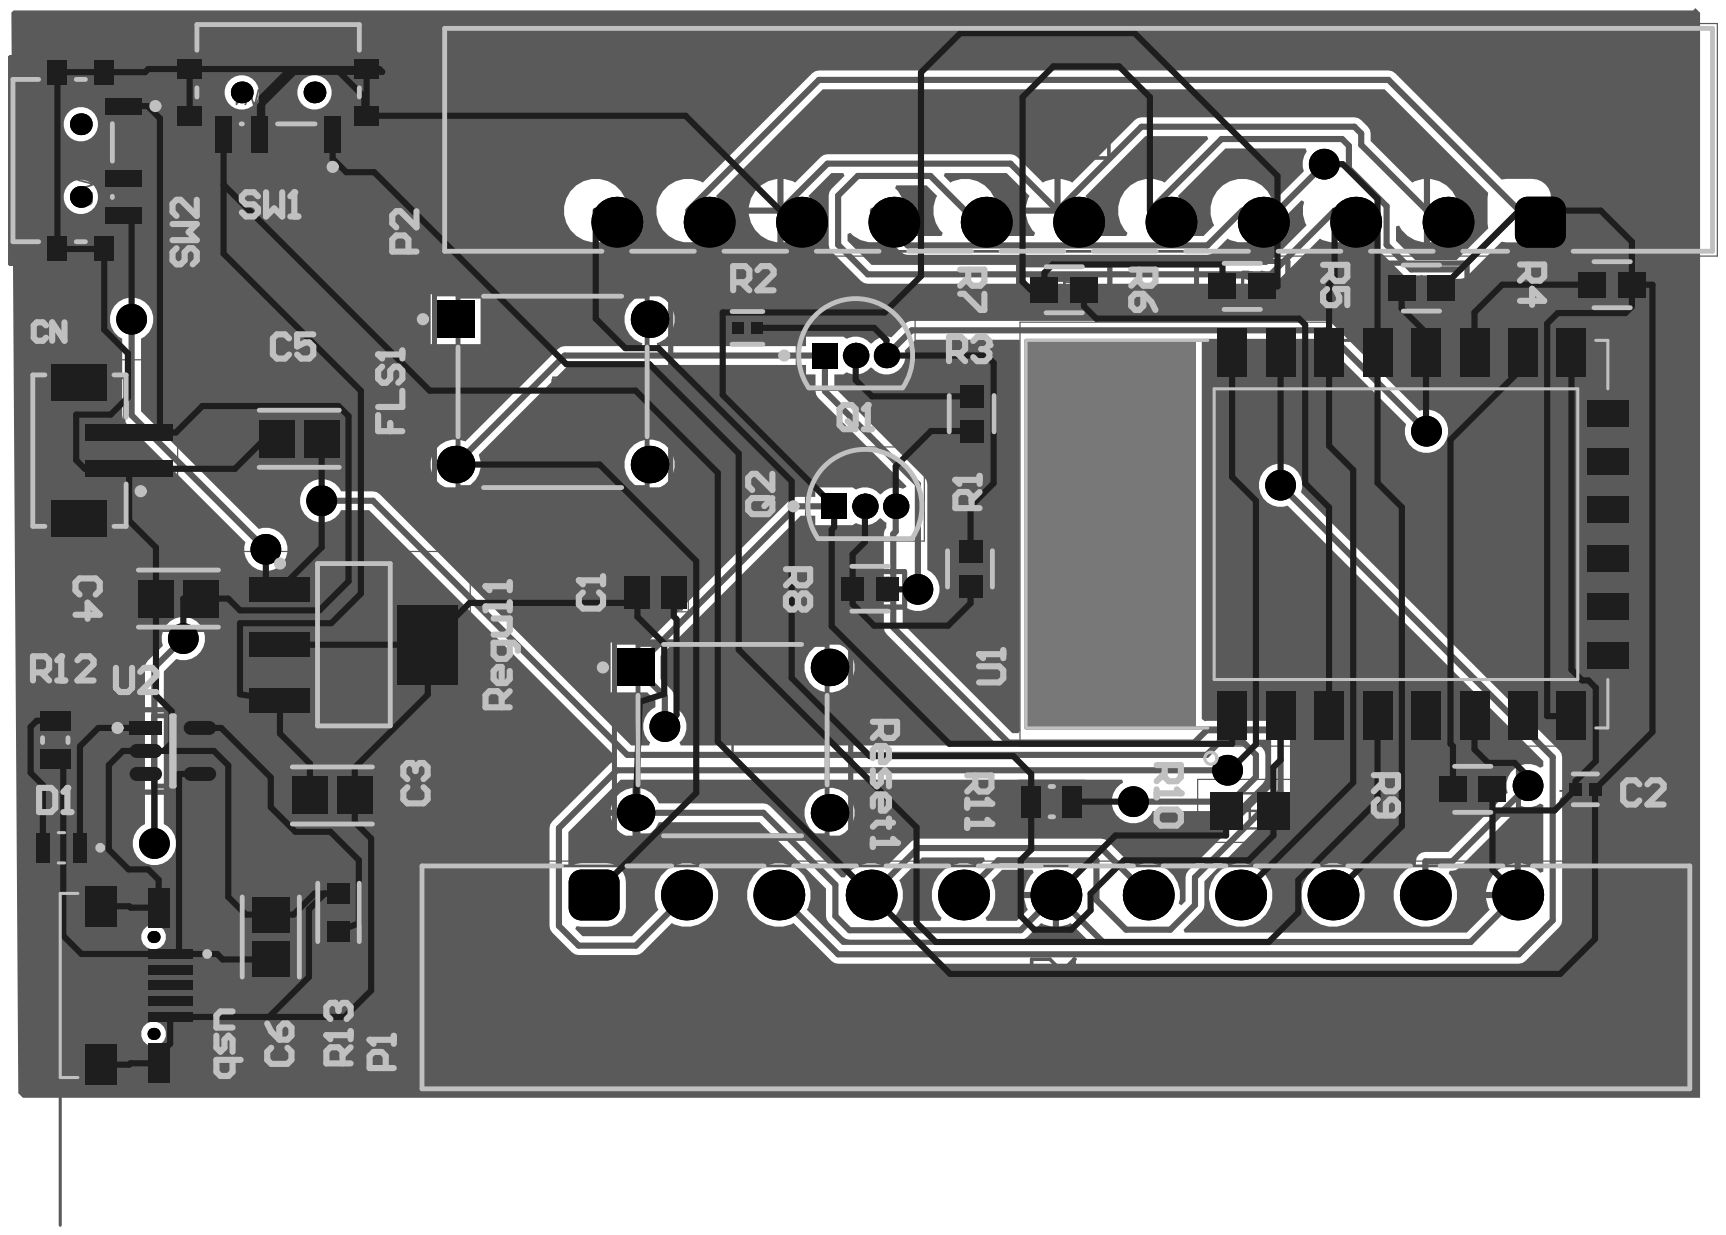
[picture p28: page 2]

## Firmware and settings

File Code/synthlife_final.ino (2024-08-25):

#include <Wire.h>
#include <MAX30100_PulseOximeter.h>
#include <DFRobot_MLX90614.h>
#include <OakOLED.h>

#define REPORTING_PERIOD_MS 1000 
#define GSR_PIN A0  // Define the GSR sensor pin


OakOLED oled;
PulseOximeter pox;
DFRobot_MLX90614_I2C mlx;

// Define the fuzzy membership functions
void gsrMembershipValue(float gsr, float &low, float &medium, float &high, float &veryHigh) {
  if (gsr <= 2.0) {
    low = 1.0;
    medium = high = veryHigh = 0.0;
  } else if (gsr <= 5.0) {
    low = (5.0 - gsr) / (5.0 - 2.0);
    medium = (gsr - 2.0) / (5.0 - 2.0);
    high = veryHigh = 0.0;
  } else if (gsr <= 8.0) {
    low = medium = (8.0 - gsr) / (8.0 - 5.0);
    medium = (gsr - 5.0) / (8.0 - 5.0);
    high = (8.0 - gsr) / (8.0 - 5.0);
    veryHigh = 0.0;
  } else {
    low = medium = high = (gsr - 8.0) / (10.0 - 8.0);
    veryHigh = 1.0;
  }
}

void tempMembershipValue(float temp, float &low, float &medium, float &high, float &veryHigh) {
  if (temp <= 34.0) {
    low = 1.0;
    medium = high = veryHigh = 0.0;
  } else if (temp <= 37.0) {
    low = (37.0 - temp) / (37.0 - 34.0);
    medium = (temp - 34.0) / (37.0 - 34.0);
    high = veryHigh = 0.0;
  } else if (temp <= 39.0) {
    low = medium = (39.0 - temp) / (39.0 - 37.0);
    medium = (temp - 37.0) / (39.0 - 37.0);
    high = (39.0 - temp) / (39.0 - 37.0);
    veryHigh = 0.0;
  } else {
    low = medium = high = (temp - 39.0) / (42.0 - 39.0);
    veryHigh = 1.0;
  }
}

void hrMembershipValue(float hr, float &low, float &medium, float &high, float &veryHigh) {
  if (hr <= 60.0) {
    low = 1.0;
    medium = high = veryHigh = 0.0;
  } else if (hr <= 80.0) {
    low = (80.0 - hr) / (80.0 - 60.0);
    medium = (hr - 60.0) / (80.0 - 60.0);
    high = veryHigh = 0.0;
  } else if (hr <= 100.0) {
    low = medium = (100.0 - hr) / (100.0 - 80.0);
    medium = (hr - 80.0) / (100.0 - 80.0);
    high = (100.0 - hr) / (100.0 - 80.0);
    veryHigh = 0.0;
  } else {
    low = medium = high = (hr - 100.0) / (120.0 - 100.0);
    veryHigh = 1.0;
  }
}

// Fuzzy associative memory based on the research
String getStressState(float gsrLow, float gsrMedium, float gsrHigh, float gsrVeryHigh,
                      float tempLow, float tempMedium, float tempHigh, float tempVeryHigh,
                      float hrLow, float hrMedium, float hrHigh, float hrVeryHigh) {
  String gsrState = gsrLow > max(gsrMedium, max(gsrHigh, gsrVeryHigh)) ? "Low" :
                     (gsrMedium > max(gsrHigh, gsrVeryHigh)) ? "Medium" :
                     (gsrHigh > gsrVeryHigh) ? "High" : "Very High";

  String tempState = tempLow > max(tempMedium, max(tempHigh, tempVeryHigh)) ? "Low" :
                      (tempMedium > max(tempHigh, tempVeryHigh)) ? "Medium" :
                      (tempHigh > tempVeryHigh) ? "High" : "Very High";

  String hrState = hrLow > max(hrMedium, max(hrHigh, hrVeryHigh)) ? "Low" :
                    (hrMedium > max(hrHigh, hrVeryHigh)) ? "Medium" :
                    (hrHigh > hrVeryHigh) ? "High" : "Very High";

  if (gsrState == "Low") {
    if (tempState == "Low") {
      if (hrState == "Low") return "Relax";
      else return "Anxious";
    } else if (tempState == "Medium") {
      if (hrState == "Low") return "Relax";
      else if (hrState == "Medium") return "Calm";
      else return "Anxious";
    } else if (tempState == "High" || tempState == "Very High") {
      if (hrState == "Low") return "Relax";
      else if (hrState == "Medium" || hrState == "High") return "Calm";
      else return "Anxious";
    }
  } else if (gsrState == "Medium") {
    if (tempState == "Low") {
      if (hrState == "Very High") return "Stress";
      else return "Anxious";
    } else if (tempState == "Medium" || tempState == "High") {
      if (hrState == "Low" || hrState == "Medium") return "Calm";
      else return "Anxious";
    } else if (tempState == "Very High") {
      if (hrState == "Low") return "Relax";
      else if (hrState == "Very High") return "Relax";
      else return "Calm";
    }
  } else if (gsrState == "High") {
    if (tempState == "Low") {
      if (hrState == "Low") return "Anxious";
      else if (hrState == "Medium") return "Calm";
      else return "Anxious";
    } else if (tempState == "Medium") {
      if (hrState == "Low") return "Anxious";
      else if (hrState == "Medium" || hrState == "High") return "Anxious";
    } else if (tempState == "High" || tempState == "Very High") {
      if (hrState == "Low" || hrState == "Medium") return "Calm";
      else return "Anxious";
    }
  } else if (gsrState == "Very High") {
    if (tempState == "Low" || tempState == "Medium" || tempState == "High") {
      if (hrState == "High" || hrState == "Very High") return "Stress";
      else return "Anxious";
    } else if (tempState == "Very High") {
      if (hrState == "Low" || hrState == "Medium") return "Calm";
      else return "Anxious";
    }
  }
  return "Unknown"; // In case no match is found (shouldn't happen)
}

// Map the stress state to a score
int getStressScore(String stressState, float membershipValue) {
  if (stressState == "Relax") {
    return map(membershipValue * 100, 0, 100, 1, 25);  // Relax: 1-25
  } else if (stressState == "Calm") {
    return map(membershipValue * 100, 0, 100, 26, 50); // Calm: 26-50
  } else if (stressState == "Anxious") {
    return map(membershipValue * 100, 0, 100, 51, 75); // Anxious: 51-75
  } else if (stressState == "Stress") {
    return map(membershipValue * 100, 0, 100, 76, 100); // Stress: 76-100
  } else {
    return 0;  // Default value in case of error
  }
}

void setup() 
{
  Serial.begin(9600);
  mlx.begin();
  oled.begin();
  pox.begin();
  Wire.setClock(100000);     
}                      

void loop()
{
  pox.update();
  static uint32_t tsLastReport = 0;
  if (millis() - tsLastReport > REPORTING_PERIOD_MS) {
    //Serial.print("Heart BPM: ");
    //Serial.print(pox.getHeartRate());
    //Serial.print(" Oxygen Percent: ");
    //Serial.println(pox.getSpO2());
    float spo2Value = pox.getSpO2();
    float hrValue = pox.getHeartRate();
    float tempValue = mlx.getObjectTempCelsius();
    float gsrValue = analogRead(GSR_PIN);

    // Calculate membership values
    float gsrLow, gsrMedium, gsrHigh, gsrVeryHigh;
    gsrMembershipValue(gsrValue, gsrLow, gsrMedium, gsrHigh, gsrVeryHigh);

    float tempLow, tempMedium, tempHigh, tempVeryHigh;
    tempMembershipValue(tempValue, tempLow, tempMedium, tempHigh, tempVeryHigh);

    float hrLow, hrMedium, hrHigh, hrVeryHigh;
    hrMembershipValue(hrValue, hrLow, hrMedium, hrHigh, hrVeryHigh);

    // Determine the stress state
    String stressState = getStressState(gsrLow, gsrMedium, gsrHigh, gsrVeryHigh,
                                        tempLow, tempMedium, tempHigh, tempVeryHigh,
                                        hrLow, hrMedium, hrHigh, hrVeryHigh);

    // Calculate membership value for the stress state
    float membershipValue = max(max(gsrLow, gsrMedium), max(gsrHigh, gsrVeryHigh));
    membershipValue = max(membershipValue, max(max(tempLow, tempMedium), max(tempHigh, tempVeryHigh)));
    membershipValue = max(membershipValue, max(max(hrLow, hrMedium), max(hrHigh, hrVeryHigh)));

    // Map the stress state to a score within a range
    int stressScore = getStressScore(stressState, membershipValue);


    oled.clearDisplay();
    oled.setCursor(0, 0);
    oled.print("BPM: ");
    oled.print(hrValue);
    oled.setCursor(70, 0);
    oled.print("SPO2: ");
    oled.print(spo2Value);

    //float ambientTemp = mlx.getAmbientTempCelsius();
    //Serial.print(" ----- Temperature: ");
    //Serial.println(temp);
    oled.setCursor(0, 15);
    oled.print("TEMP: ");
    oled.println(tempValue);
    

    // Read and display GSR sensor value
    
    //Serial.print("GSR Value: ");
    //Serial.println(gsrValue);
    oled.setCursor(0, 35);
    oled.print("GSR: ");
    oled.println(gsrValue/20);

    oled.setCursor(0, 45);
    oled.println("Current State- ");
    
    oled.setCursor(0, 55);
    oled.println(stressState);
    

    oled.display();
    tsLastReport = millis();
    delay(5000);

  
  }
}

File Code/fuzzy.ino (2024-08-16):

#include <Fuzzy.h> // Ensure you have a fuzzy logic library compatible with Arduino

// Create fuzzy objects
Fuzzy* fuzzy = new Fuzzy();

void setup() {
    Serial.begin(9600);

    // Define fuzzy input variables
    FuzzySet* gsrLow = new FuzzySet(0, 0, 1.7, 2.0);
    FuzzySet* gsrMedium = new FuzzySet(1.7, 2.0, 4.0, 4.3);
    FuzzySet* gsrHigh = new FuzzySet(4.0, 4.3, 6.0, 6.3);
    FuzzySet* gsrVeryHigh = new FuzzySet(6.0, 6.3, 10.0, 10.0);
    
    FuzzyInput* GSR = new FuzzyInput(1);
    GSR->addFuzzySet(gsrLow);
    GSR->addFuzzySet(gsrMedium);
    GSR->addFuzzySet(gsrHigh);
    GSR->addFuzzySet(gsrVeryHigh);
    fuzzy->addFuzzyInput(GSR);

    FuzzySet* tempLow = new FuzzySet(30.0, 30.0, 32.0, 33.0);
    FuzzySet* tempMedium = new FuzzySet(32.0, 33.0, 34.5, 35.5);
    FuzzySet* tempHigh = new FuzzySet(35.0, 35.5, 36.5, 37.0);
    FuzzySet* tempVeryHigh = new FuzzySet(36.5, 37.5, 40.0, 40.0);
    
    FuzzyInput* body_temp = new FuzzyInput(2);
    body_temp->addFuzzySet(tempLow);
    body_temp->addFuzzySet(tempMedium);
    body_temp->addFuzzySet(tempHigh);
    body_temp->addFuzzySet(tempVeryHigh);
    fuzzy->addFuzzyInput(body_temp);

    FuzzySet* hrLow = new FuzzySet(50.0, 50.0, 65.0, 70.0);
    FuzzySet* hrMedium = new FuzzySet(65.0, 70.0, 85.0, 90.0);
    FuzzySet* hrHigh = new FuzzySet(85.0, 90.0, 95.0, 100.0);
    FuzzySet* hrVeryHigh = new FuzzySet(95.0, 100.0, 150.0, 150.0);
    
    FuzzyInput* heart_rate = new FuzzyInput(3);
    heart_rate->addFuzzySet(hrLow);
    heart_rate->addFuzzySet(hrMedium);
    heart_rate->addFuzzySet(hrHigh);
    heart_rate->addFuzzySet(hrVeryHigh);
    fuzzy->addFuzzyInput(heart_rate);

    // Define fuzzy output variable
    FuzzySet* relax = new FuzzySet(0.0, 0.0, 20.0, 25.0);
    FuzzySet* calm = new FuzzySet(22.5, 25.0, 45.0, 52.5);
    FuzzySet* anxious = new FuzzySet(47.5, 50.0, 75.0, 77.5);
    FuzzySet* stress = new FuzzySet(72.5, 75.0, 100.0, 100.0);
    
    FuzzyOutput* stress_level = new FuzzyOutput(1);
    stress_level->addFuzzySet(relax);
    stress_level->addFuzzySet(calm);
    stress_level->addFuzzySet(anxious);
    stress_level->addFuzzySet(stress);
    fuzzy->addFuzzyOutput(stress_level);

    // Define fuzzy rules
    
    //Rule 1: IF GSR is low AND body_temp is low AND heart_rate is low THEN stress_level is relax
    FuzzyRuleAntecedent* ifGsrLowAndTempLowAndHrLow = new FuzzyRuleAntecedent();
    ifGsrLowAndTempLowAndHrLow->joinWithAND(gsrLow, tempLow);
    ifGsrLowAndTempLowAndHrLow->joinWithAND(ifGsrLowAndTempLowAndHrLow, hrLow);

    FuzzyRuleConsequent* thenRelax = new FuzzyRuleConsequent();
    thenRelax->addOutput(relax);

    FuzzyRule* fuzzyRule1 = new FuzzyRule(1, ifGsrLowAndTempLowAndHrLow, thenRelax);
    fuzzy->addFuzzyRule(fuzzyRule1);

    //Rule 2: IF GSR is low AND body_temp is low AND heart_rate is Medium THEN stress_level is anxious
    FuzzyRuleAntecedent* ifGsrLowAndTempLowAndHrMid = new FuzzyRuleAntecedent();
    ifGsrLowAndTempLowAndHrMid->joinWithAND(gsrLow, tempLow);
    ifGsrLowAndTempLowAndHrMid->joinWithAND(ifGsrLowAndTempLowAndHrMid, hrMedium);

    FuzzyRuleConsequent* thenAnxious = new FuzzyRuleConsequent();
    thenAnxious->addOutput(anxious);

    FuzzyRule* fuzzyRule2 = new FuzzyRule(2,  ifGsrLowAndTempLowAndHrMid, thenAnxious);
    fuzzy->addFuzzyRule(fuzzyRule2);

    //Rule 3: IF GSR is low AND body_temp is low AND heart_rate is high THEN stress_level is anxious
    FuzzyRuleAntecedent* ifGsrLowAndTempLowAndHrHigh = new FuzzyRuleAntecedent();
    ifGsrLowAndTempLowAndHrHigh->joinWithAND(gsrLow, tempLow);
    ifGsrLowAndTempLowAndHrHigh->joinWithAND(ifGsrLowAndTempLowAndHrHigh, hrHigh);

    FuzzyRuleConsequent* thenAnxious = new FuzzyRuleConsequent();
    thenAnxious->addOutput(anxious);

    FuzzyRule* fuzzyRule3 = new FuzzyRule(3,  ifGsrLowAndTempLowAndHrHigh, thenAnxious);
    fuzzy->addFuzzyRule(fuzzyRule3);

    //Rule 4: IF GSR is low AND body_temp is low AND heart_rate is very_high THEN stress_level is anxious
    FuzzyRuleAntecedent* ifGsrLowAndTempLowAndHrVeryHigh = new FuzzyRuleAntecedent();
    ifGsrLowAndTempLowAndHrVeryHigh->joinWithAND(gsrLow, tempLow);
    ifGsrLowAndTempLowAndHrVeryHigh->joinWithAND(ifGsrLowAndTempLowAndHrVeryHigh, hrVeryHigh);

    FuzzyRuleConsequent* thenAnxious = new FuzzyRuleConsequent();
    thenAnxious->addOutput(anxious);

    FuzzyRule* fuzzyRule4 = new FuzzyRule(4,  ifGsrLowAndTempLowAndHrVeryHigh, thenAnxious);
    fuzzy->addFuzzyRule(fuzzyRule4);

    //Rule 5: IF GSR is low AND body_temp is medium AND heart_rate is low THEN stress_level is relax

    FuzzyRuleAntecedent* ifGsrLowAndTempMidAndHrLow = new FuzzyRuleAntecedent();
    ifGsrLowAndTempMidAndHrLow->joinWithAND(gsrLow, tempMedium);
    ifGsrLowAndTempMidAndHrLow->joinWithAND(ifGsrLowAndTempMidAndHrLow, hrLow);

    FuzzyRuleConsequent* thenAnxious = new FuzzyRuleConsequent();
    thenRelax->addOutput(relax);

    FuzzyRule* fuzzyRule5 = new FuzzyRule(5,  ifGsrLowAndTempMidAndHrLow, thenRelax);
    fuzzy->addFuzzyRule(fuzzyRule5);

    //Rule 6: IF GSR is low AND body_temp is medium AND heart_rate is medium THEN stress_level is calm
    FuzzyRuleAntecedent* ifGsrLowAndTempMidAndHrMid = new FuzzyRuleAntecedent();
    ifGsrLowAndTempMidAndHrMid->joinWithAND(gsrLow, tempMedium);
    ifGsrLowAndTempMidAndHrMid->joinWithAND(ifGsrLowAndTempMidAndHrMid, hrMedium);

    FuzzyRuleConsequent* thenCalm = new FuzzyRuleConsequent();
    thenCalm->addOutput(calm);

    FuzzyRule* fuzzyRule6 = new FuzzyRule(6,  ifGsrLowAndTempLowAndHrVeryHigh, thenCalm);
    fuzzy->addFuzzyRule(fuzzyRule6);

    // Rule 7: IF GSR is low AND body_temp is medium AND heart_rate is lhigh THEN stress_level is anxious
    FuzzyRuleAntecedent* ifGsrLowAndTempMidAndHrHigh = new FuzzyRuleAntecedent();
    ifGsrLowAndTempMidAndHrHigh->joinWithAND(gsrLow, tempMedium);
    ifGsrLowAndTempMidAndHrHigh->joinWithAND(ifGsrLowAndTempMidAndHrHigh, hrHigh);

    FuzzyRuleConsequent* thenAnxious = new FuzzyRuleConsequent();
    thenAnxious->addOutput(anxious);

    FuzzyRule* fuzzyRule7 = new FuzzyRule(7,  ifGsrLowAndTempMidAndHrHigh, thenAnxious);
    fuzzy->addFuzzyRule(fuzzyRule7);

    //Rule 8: IF GSR is low AND body_temp is medium AND heart_rate is very_high THEN stress_level is anxious
    FuzzyRuleAntecedent* ifGsrLowAndTempMidAndHrVeryHigh = new FuzzyRuleAntecedent();
    ifGsrLowAndTempMidAndHrVeryHigh->joinWithAND(gsrLow, tempMedium);
    ifGsrLowAndTempMidAndHrVeryHigh->joinWithAND(ifGsrLowAndTempMidAndHrVeryHigh, hrVeryHigh);

    FuzzyRuleConsequent* thenAnxious = new FuzzyRuleConsequent();
    thenAnxious->addOutput(anxious);

    FuzzyRule* fuzzyRule8 = new FuzzyRule(8,  ifGsrLowAndTempLowAndHrVeryHigh, thenAnxious);
    fuzzy->addFuzzyRule(fuzzyRule8);
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

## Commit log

2024-08-16 Add files via upload
    Python program to Calculate Stress Level using GSR , Body Temperature and Heart beat
2025-04-16 PCB documents
    [Bill of Materials-PCB2.xlsx, PCB2.PcbDoc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]
2025-04-16 Create Enclosure
